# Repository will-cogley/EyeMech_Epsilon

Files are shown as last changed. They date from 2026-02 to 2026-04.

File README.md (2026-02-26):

# EYEMECH ε3.2 Assembly Guide  
**NM Robotics**

Fully 3D-printable animatronic eye mechanism compatible with hobby electronics and micro servos.

---

## Overview

The **EYEMECH ε3.2** mechanism can be entirely 3D printed and built using common hobby electronics.

Recommended components and community:

- Website: https://nmrobots.com/
- Discord: https://discord.gg/qXKNRgHKNB  

---

# Parts, Tools & Requirements

## Skill Level

Suitable for experienced beginners in 3D printing and electronics.

- Some dexterity required
- Support removal can be delicate

---

## Required Parts

### Servos (6x Micro Servos)

Choose one:

- **M0090** — Quiet, strong, sturdy - our new favourite and possibly our new standard in the future
- **SG90** — Low cost, weaker/slower  
- **MG90s** — Recommended balance of cost and power  

> Other similar-form servos may work but are not fully tested.

---

### Eyes (2x)

Choose one:

- Realistic Eyes  
- Ultra Realistic Eyes  
- DIY 3D printed eyes  

---

### Controller

- 1x Eye Mechanism Controller Board  
- Optional: 1x Handheld Controller Board  

---

### Budget Alternative

Instead of the official board:

- Raspberry Pi Pico  
- Breadboard  
- Jumper wires  
- Two-way switch  

Note: Reliability may be reduced compared to the dedicated board.

---

## Tools

- Reliable 3D printer  
- PLA filament (quality recommended)  
- Scraper tool (for supports)  
- **Data-capable USB cable** (not power-only)

---

# Selecting a Design

Two variants are available:

| Factor | ε2 (Snap-fit) | ε3.2-PIP (Print-in-place) |
|---|---|---|
| Ease of Printing | ⭐⭐⭐⭐ | ⭐⭐⭐ |
| Post-processing | ⭐⭐⭐⭐⭐ | ⭐⭐⭐ |
| Ease of Assembly | ⭐⭐ | ⭐⭐⭐⭐⭐ |
| Accuracy | ⭐⭐⭐⭐ | ⭐⭐⭐ |

### Recommendation

If unsure:

- Use **MG90s servos**
- Choose **ε3.2-PIP (Print-in-place)**

---

## Servo Fit Test

Due to servo manufacturing variations:

1. Print the **servo fitting block**
2. Test which hole fits best
3. Select the matching lettered parts
4. Fit should be tight but not damaging

---

# Manufacture

All parts fit on a Bambu X-1 Carbon or P1 series printer.

### Print Settings

- PLA recommended
- 0.2mm layer height
- Organic/tree supports recommended
- Ensure pivot rods/rings are parallel to bed
- For ε2: pivot openings facing down

---

# Post-Processing

- Remove supports carefully
- Avoid stressing delicate pivot features

---

# Assembly (ε3.2-PIP)

Video guide:  
https://youtu.be/MeHLouL9ltw  

---

## Assembly Overview

1. Insert servo into **X-Axis Subassembly A**
2. Clip **Y-Axis Subassembly** on top
3. Attach central pivot holders
4. Attach **X-Axis Subassembly B** (leave loose)
5. Snap assembly into main base
6. Attach eyes
7. Attach eyelids (top = short levers, bottom = long)
8. Snap outer eyelid pivots underneath base
9. Install remaining 5 servos
10. Secure with retainers
11. Insert PCB holders
12. Snap PCB into place

---

# Wiring & Code

Compatible with:

- NM Robotics β1.2 EyeMech Board  
- Raspberry Pi Pico  

---

## Firmware Installation

1. Download MicroPython firmware:  
   https://micropython.org/download/RPI_PICO/

2. Install Thonny IDE:  
   https://thonny.org/

3. Hold **BOOT** while plugging Pico into PC  
4. Copy `.uf2` firmware to device  

Official guide:  
https://www.raspberrypi.com/documentation/microcontrollers/micropython.html

---

## Required Libraries

Install via Thonny:

- picozero  
- micropython-servo  

Steps:

1. Select interpreter  
2. Tools → Manage Packages  
3. Install from local file  

---

## Uploading Code

1. Open `EyeMechEpsilon3.py`
2. Run to confirm no errors
3. Save as `main.py` on Pico

This enables auto-run on boot.

---

## Servo Wiring (Without Official Board)

| Pico Pin | Connect To |
|---|---|
| VBUS (5V) | Servo Power (Red) |
| GND | Servo GND (Black/Brown) |
| GPIO10 | Left/Right |
| GPIO11 | Up/Down |
| GPIO12 | Top Left |
| GPIO13 | Bottom Left |
| GPIO14 | Top Right |
| GPIO15 | Bottom Right |
| GPIO7 | Mode Switch → GND |

---

# Calibration

1. Set board to **Hold**
2. Power on
3. Eyes centered and forward
4. Lids closed meeting in middle
5. Secure servo horns

Up/Down servo may need temporary removal for access.

---

# Operation

- **Move Mode** → Random movement  
- **Controller Connected** → Manual mode  
  - Joystick = Eye direction  
  - Button = Blink  
  - Rear slider = Default eyelid openness  

---

# Support

- https://nmrobots.com/
- https://discord.gg/qXKNRgHKNB

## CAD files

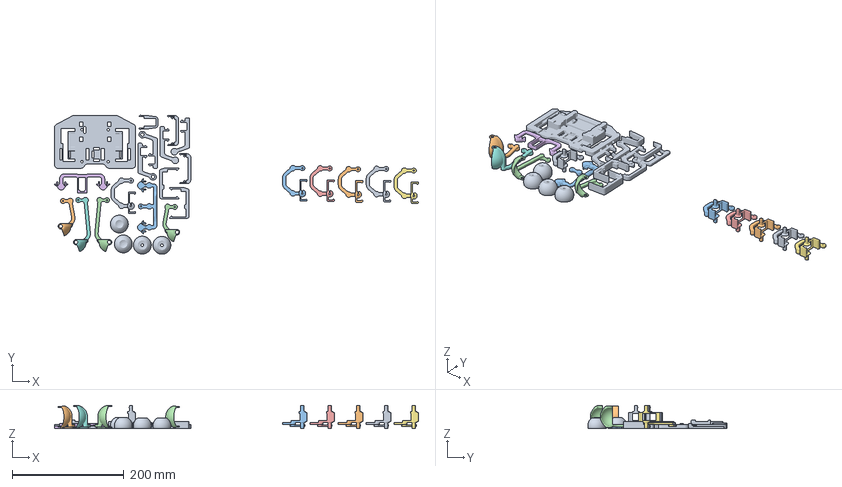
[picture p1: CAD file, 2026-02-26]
3D Prints/EyeMech e4.0 Changed 4 Lids and 2 Central bars.3mf
651.9 x 249.7 x 42.0 mm
Assembly
EyeMech ε3.2.1 0.075.stl
Sub-merged body
EyeMech ε3.2.2 0.1.stl
EyeMech ε3.2.1 0.025.stl
EyeMech ε3.2.1 0.05.stl

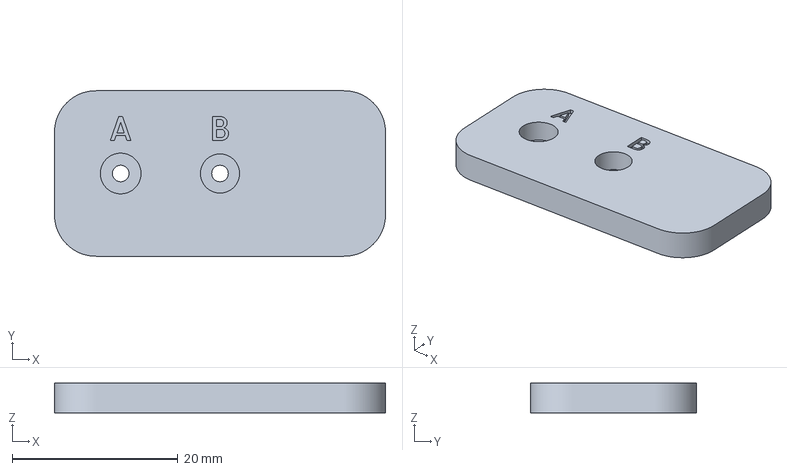
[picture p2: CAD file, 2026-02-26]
3D Prints/EyeMech ε3.2 Testing Plate.3mf
40.0 x 20.0 x 3.60 mm

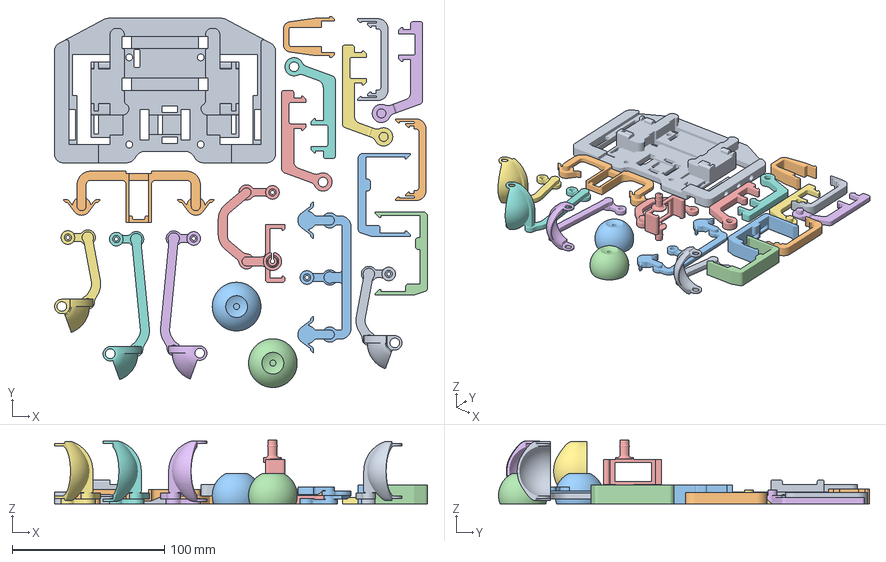
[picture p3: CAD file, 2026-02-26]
3D Prints/EyeMech ε3.2 SG90 - B.3mf
245.3 x 243.7 x 42.0 mm
SnapEyemech v20 x 6
Base x 2
Base_1
Base_2
EyeMech ε3.1 BE
EyeMech ε3.1 BD
EyeMech ε3.1 BC
EyeMech ε3.1 BB
EyeMech ε3.1 BA
Assembly
EyeMech ε3.1 2222.step

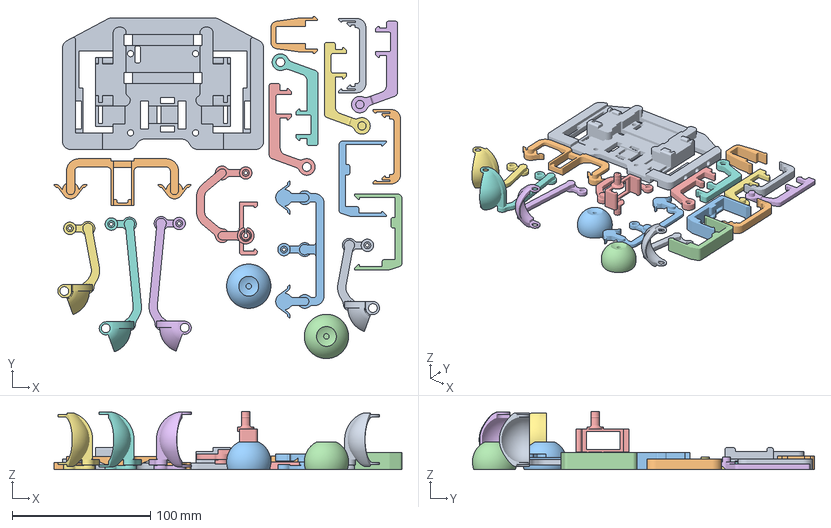
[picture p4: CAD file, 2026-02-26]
3D Prints/EyeMech ε3.2 SG90 - A.3mf
251.4 x 247.2 x 42.0 mm
SnapEyemech v20 x 6
Base x 2
Base_1
Base_2
EyeMech ε3.1 AG
EyeMech ε3.1 AD
EyeMech ε3.1 AC
EyeMech ε3.1 AB
EyeMech ε3.1 AA
Assembly
EyeMech ε3.1 111.step

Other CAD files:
3D Prints/EyeMech ε3.2 MG90s - B.3mf
3D Prints/EyeMech ε3.2 MG90s - A.3mf

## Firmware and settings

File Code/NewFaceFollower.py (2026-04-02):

"""
Will Cogley's Eye Mechanism control code
Requires the micropython-servo and picozero libraries
https://pypi.org/project/micropython-servo/
https://pypi.org/project/picozero/
"""

import time
from machine import Pin, I2C, ADC, UART
from servo import Servo
from picozero import Button
import time, random, ujson, urandom, sys, select, uselect, math

# Set up the switches and potentiometers
led_red = Pin(25, Pin.OUT)
enable = Pin(6, Pin.IN, Pin.PULL_UP)
mode = Pin(7, Pin.IN, Pin.PULL_UP)
rx_pin = Pin(1, Pin.IN, Pin.PULL_UP)
blink_pin = Pin(9, Pin.IN, Pin.PULL_UP)
UD = ADC(26)
trim = ADC(27)
LR = ADC(28)
#uart1 = UART(0, baudrate=921600, tx=Pin(0), rx=Pin(1))

INVOKE_INTERVAL_MS = 500 # Adjust this: faster interval means more frames/sec
INVOKE_CMD = b"AT+INVOKE=1,0,1\r"
cbuf = []
readflag = True
staticflag = False
last_boxes = None
detected_flag = False
static_target = 200
static_timer = static_target
idle_flag = False
idle_pause = 300


deadzone = 3
x_offset = 0
y_offset = 0
x_adj_factor = 10
y_adj_factor = 10
pixel_centre = 112
tl_target = 90
tr_target = 90
bl_target = 90
br_target = 90


# Define servos
servos = {
    "LR": Servo(pin_id=10),
    "UD": Servo(pin_id=11),
    "TL": Servo(pin_id=12),
    "BL": Servo(pin_id=13),
    "TR": Servo(pin_id=14),
    "BR": Servo(pin_id=15),
}

# Min, Max
servo_limits = {
    "LR": (40, 140),   
    "UD": (40, 140),
    "TL": (90, 170),
    "BL": (90, 10),
    "TR": (90, 10),
    "BR": (90, 160),
}

# Set all servos to central position for assembly
def calibrate():
    for name, servo in servos.items():
#         print("neutral position")  # Debug output
        servo.write(90)

# Neutral pose
def neutral():
    eyes = list(servos.keys())[2:]  # Get last 4 servo names
    for name, servo in servos.items():
        servo.write(90)
    lids = list(servos.keys())[-4:]  # Get last 4 servo names
    for servo in lids:
        max_angle = servo_limits[servo][1]  # Get max angle
        servos[servo].write(max_angle)  # Move to min      
          
def blink():
    servos["TL"].write(servo_limits["TL"][0])
    servos["TR"].write(servo_limits["TR"][0])
    servos["BL"].write(servo_limits["BL"][0])
    servos["BR"].write(servo_limits["BR"][0])
        
def open_lid():        
    servos["TL"].write(tl_target)
    servos["TR"].write(tr_target)
    servos["BL"].write(bl_target)
    servos["BR"].write(br_target)  
        
def control_ud_and_lids(ud_angle): # Moves UD servo and makes TL/TR follow instantly based on UD's position
    global tl_target, tr_target, bl_target, br_target
    # Get limits
    ud_min, ud_max = servo_limits["UD"]
    tl_min, tl_max = servo_limits["TL"]
    tr_min, tr_max = servo_limits["TR"]
    bl_min, bl_max = servo_limits["BL"]
    br_min, br_max = servo_limits["BR"]

    # Normalize UD position to a 0-1 range
    ud_progress = (ud_angle - ud_min) / (ud_max - ud_min)  # 0 (min) → 1 (max)
    
    # Find target positions
    tl_target = tl_max - ((tl_max - tl_min)*(0.8*(1-ud_progress)))
    tr_target = tr_max + ((tr_min - tr_max)*(0.8*(1-ud_progress)))
    bl_target = bl_max + ((bl_min - bl_max)*(0.4*(ud_progress)))
    br_target = br_max - ((br_max - br_min)*(0.4*(ud_progress)))
   
# Move all servos instantly
    servos["UD"].write(ud_angle)
    servos["TL"].write(tl_target)
    servos["TR"].write(tr_target)
    servos["BL"].write(bl_target)
    servos["BR"].write(br_target)

def scale_potentiometer(pot_value, servo, reverse=False):
    # Scale potentiometer value to UD range (50 to 130)
    in_min = 300
    in_max = 65300
    min_limit = servo_limits[servo][0]
    max_limit = servo_limits[servo][1]
    
    # Scale the potentiometer input to the servo range
    scaled_value = min_limit + (pot_value - in_min) * (max_limit - min_limit) / (in_max - in_min)
    if reverse:
       scaled_value = max_limit - (scaled_value - min_limit)
    return scaled_value


def map_value(value, in_min, in_max, out_min, out_max):
    # Map the value
    mapped = (value - in_min) * (out_max - out_min) / (in_max - in_min) + out_min
    return mapped
       
def update_eyelid_limits(trim_value):
    # Define the trim value range
    trim_min = 7000
    trim_max = 14500
    
    # Target max ranges for each eyelid servo
    TL_max_range = (130, 170)  # from most closed to most open
    BR_max_range = (130, 170)
    BL_max_range = (50, 10)    # reversed range
    TR_max_range = (50, 10)
    
    # Scale trim_value to target max ranges
    trim_progress = (trim_value - trim_min) / (trim_max - trim_min)  # 0 (closed) to 1 (open)
    trim_progress = max(0, min(1, trim_progress))  # Clamp to [0, 1] range

    # Update servo limits
    servo_limits["TL"] = (90, TL_max_range[0] + (TL_max_range[1] - TL_max_range[0]) * trim_progress)
    servo_limits["BR"] = (90, BR_max_range[0] + (BR_max_range[1] - BR_max_range[0]) * trim_progress)
    servo_limits["BL"] = (90, BL_max_range[0] + (BL_max_range[1] - BL_max_range[0]) * trim_progress)
    servo_limits["TR"] = (90, TR_max_range[0] + (TR_max_range[1] - TR_max_range[0]) * trim_progress)

class Comms:
    def __init__(self):
        # Hardware Initialization
        self.grove = UART(0, baudrate=921600, tx=Pin(0), rx=Pin(1))
        #self.esp = UART(1, baudrate=115200, tx=Pin(4), rx=Pin(5))
        
        # Constants
        self.INVOKE_CMD = b"AT+INVOKE=1,0,1\r"
        self.pixel_centre = 112
        self.deadzone = 20
        self.x_adj_factor = 10
        self.y_adj_factor = 10
        self.staticflag = False
        
        # Buffers and State
        self.cbuf = b""
        self.rx_buffer = b""
        self.readflag = True
        self.last_boxes = None
        
        self.grove.write(self.INVOKE_CMD)
        self.grove_vision_module = False

    def map_value(self, value, in_min, in_max, out_min, out_max):
        return (value - in_min) * (out_max - out_min) / (in_max - in_min) + out_min

    def grove_read(self):
        # State 1: Requesting data
        if self.readflag:
            # Flush existing buffer quickly
            while self.grove.any():
                self.grove.read()
                self.grove_vision_module = True
            self.grove.write(self.INVOKE_CMD)
            self.cbuf = b""
            self.readflag = False
            return None # Return early, data isn't ready yet

        # State 2: Receiving data
        if self.grove.any():
            # PERFORMANCE: Read chunks directly instead of looping char by char
            self.cbuf += self.grove.read()
            
            # Wait until the end of the JSON packet arrives
            if b'"resolution"' in self.cbuf:
                key = b'"boxes":'
                i = self.cbuf.find(key)
                
                if i != -1:
                    boxes_part = self.cbuf[i + len(key):]
                    
                    # Ensure we have the closing bracket before slicing
                    end_idx = boxes_part.find(b']')
                    if end_idx != -1:
                        boxes_part = boxes_part[:end_idx + 1].strip()
                        
                        # Process if we have valid, new box data
                        if boxes_part != b'[]' and boxes_part != self.last_boxes:
                            self.staticflag = False
                            self.last_boxes = boxes_part
                            boxes_str = boxes_part.decode('utf-8').strip('[]')
                            
                            try:
                                numbers = [int(n) for n in boxes_str.split(',')]
                                x_offset = numbers[0] - self.pixel_centre
                                y_offset = numbers[1] - self.pixel_centre
                                
                                # Reset for next read
                                self.cbuf = b""
                                self.readflag = True
                                return x_offset, y_offset
                                
                            except ValueError:
                                # Handle cases where split data isn't a perfect integer
                                pass
                        else:
                            # Reset for next read (static or empty data)
                            self.cbuf = b""
                            self.readflag = True
                            self.staticflag = True
                            return None
                            
        return None

led_red.value(1)
x_target = 90
y_target = 90
adjustment_factor = 0

#open_lid()
neutral()

blink_time = 200
blink_time_half = blink_time / 2
blinking = False

#Detect if
comms = Comms()
time.sleep_ms(100) #wait for a short time to see if grove_vision_module flag has been set
comms.grove_read()
if comms.grove_vision_module == True:
    work_mode = "tracking"
else:
    work_mode = "auto"
    
led_red.value(0)

while True:
    work_mode_copy = work_mode
    mode_state = not mode.value()
    enable_state = not enable.value()
    if mode_state == 1: # Enter calibration mode when switch is in hold position
        work_mode = "calibration"
    else:       
        if enable_state == 1: # switch Controller mode if pin enable is true
            work_mode = "controller"
        elif work_mode == "controller": #swithch to tracking mode if already controller mode and pin enable is false  
            work_mode = "tracking"

    if work_mode == "tracking":
        if not blinking and random.randrange(20000) == 0:
            blinking = True
            blink_counter = blink_time
            
        # --- blinking state ---
        if blinking:
            if blink_counter > blink_time_half:
                blink()
            else:
                open_lid()
                
            blink_counter -= 1
            if blink_counter <= 0:
                blinking = False       
        if (offset := comms.grove_read()):
            x_offset = offset[0]
            y_offset = offset[1]
            if (x_offset < -comms.deadzone or x_offset > comms.deadzone) and not comms.staticflag:
                x_adj_value = comms.map_value(x_offset, -110, 110, x_adj_factor, -x_adj_factor)
                x_target = max(servo_limits["LR"][0],
                               min(x_target + x_adj_value, servo_limits["LR"][1]))
                servos["LR"].write(x_target)

            if (y_offset < -comms.deadzone or y_offset > comms.deadzone) and not comms.staticflag:
                y_adj_value = comms.map_value(y_offset, -110, 110, y_adj_factor, -y_adj_factor)
                y_target = max(servo_limits["UD"][0],
                               min(y_target + y_adj_value, servo_limits["UD"][1]))
            control_ud_and_lids(y_target)
    elif work_mode == "calibration":
            calibrate()
            comms.grove_read()
            work_mode = "initialisation"
    elif work_mode == "initialisation":
            blink()
            if comms.grove_vision_module == True:
                work_mode = "tracking"
            else:
                work_mode = "auto"                   
    elif work_mode == "controller":
            # Reading sensors
            UD_value = UD.read_u16()
            trim_value = trim.read_u16()
            LR_value = LR.read_u16()
            blink_state = not blink_pin.value()
    
            update_eyelid_limits(trim_value)
            
            if blink_state == 0:
                blink()
            else:
                servos["LR"].write(scale_potentiometer(LR_value, "LR", reverse = True))
                control_ud_and_lids(scale_potentiometer(UD_value, "UD"))
            time.sleep_ms(10)
    elif work_mode == "auto":
            command = random.randint(0,2)
            if command == 0:
                blink()
                time.sleep_ms(100)
            elif command == 1:
                blink()
                time.sleep_ms(100)
                control_ud_and_lids(random.randint(servo_limits["UD"][0],servo_limits["UD"][1]))
                servos["LR"].write(random.randint(servo_limits["LR"][0],servo_limits["LR"][1]))
                time.sleep_ms(random.randint(300,1000))
            elif command == 2:
                control_ud_and_lids(random.randint(servo_limits["UD"][0],servo_limits["UD"][1]))
                servos["LR"].write(random.randint(servo_limits["LR"][0],servo_limits["LR"][1]))
                time.sleep_ms(random.randint(200,400))    

    if work_mode != work_mode_copy: #if work mode has changed, open lid to initialise
        neutral()
    

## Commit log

2026-02-03 Add files via upload
    Experiments with different ways of accessing data from the Grove AI Board
2026-02-04 Update NewFaceFollower.py
    Working slowly with narrow FOV camera + blinking + lids
2026-02-13 Create IdleModeTracking.py
    Idle mode works but triggers lots of hallucinations and erratic movement. Need to add cooldown timer after random movement
2026-02-25 Added LED indication at startup
2026-02-26 add non-code files
    [EyeMech e4.0 Changed 4 Lids and 2 Central bars.3mf, EyeMech ε3.2 MG90s - A.3mf, EyeMech ε3.2 MG90s - B.3mf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]
